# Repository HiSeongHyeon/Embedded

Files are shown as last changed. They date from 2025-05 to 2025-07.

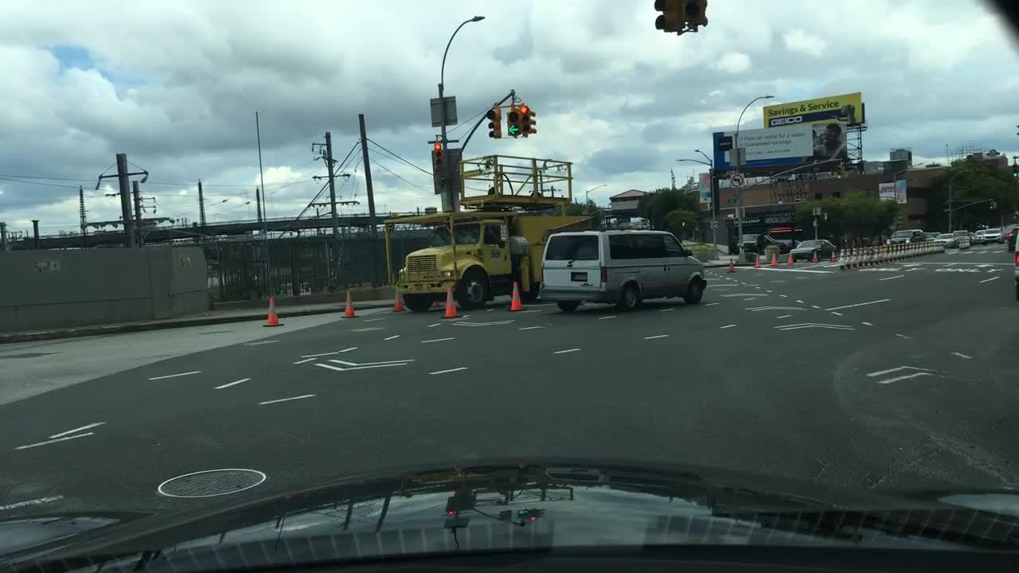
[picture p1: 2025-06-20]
src_tmp/src/glare_detection/src/test_images/00c41a61-4ba25ad4_jpg.rf.0ae1f0196ada40d85010ea932c0ebc6e.jpg

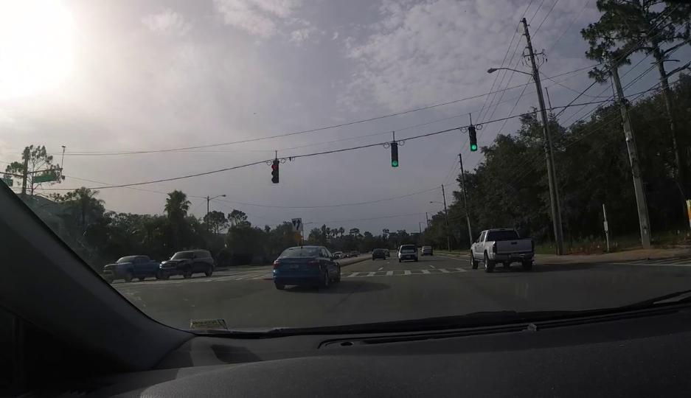
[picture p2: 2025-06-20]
src_tmp/src/glare_detection/src/test_images/vid-7-_png.rf.13047234f4ee9584bf44184de06c9a75.jpg

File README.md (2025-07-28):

# 🚗 SunVisorRobot: 차량 운전자 눈부심 방지 선바이저 로봇

**차량 운전 중 발생하는 태양 및 강한 조명으로 인한 눈부심(Glare)을 자동으로 감지하고, 지능적으로 선바이저를 제어하여 운전자의 시야를 안전하게 확보하는 임베디드 시스템 프로젝트입니다.**

## 🌟 프로젝트 목표

*   실시간으로 변화하는 외부 조명 환경에서 Glare를 정확하게 인식합니다.
*   카메라로 인식된 Glare의 위치를 운전자 시야 기준으로 정밀하게 좌표 변환합니다.
*   변환된 좌표에 따라 선바이저를 3x3 그리드 영역으로 신속하고 정확하게 이동시켜 효과적으로 눈부심을 차단합니다.
*   Raspberry Pi에서 고수준 인식 및 판단을, Arduino에서 저수준 모터 제어를 담당하는 분산 시스템으로 구현하여 실시간성과 안정성을 확보합니다.

## 🛠️ 시스템 아키텍처

본 시스템은 크게 다음과 같은 모듈로 구성됩니다:

1.  **Glare 감지 모듈 (C++ on Raspberry Pi):**
    *   Raspberry Pi 카메라 모듈 v3로부터 실시간 영상 스트림을 입력받습니다.
    *   OpenCV 라이브러리를 사용하여 HSV 색 공간 변환, 임계값 필터링, Contour 분석 등을 통해 이미지 내 Glare 영역을 탐지하고 중심 픽셀 좌표를 추출합니다.
2.  **좌표 변환 모듈 (C++ on Raspberry Pi):**
    *   Glare 감지 모듈에서 전달받은 픽셀 좌표를 입력으로 사용합니다.
    *   카메라 내부 파라미터, 렌즈 왜곡 계수, 차량 내 카메라/운전자/윈드실드의 3D 기하학적 관계를 이용하여 픽셀 좌표를 3x3 그리드 좌표 `(col, row)`로 변환합니다.
3.  **시리얼 통신 모듈 (C++ on Raspberry Pi & Arduino):**
    *   Raspberry Pi에서 Arduino로 제어 명령을 전송합니다.
    *   1바이트 통신 프로토콜 사용:
        *   비트 7: Glare 감지 유무 (1: 감지, 0: 미감지/접기)
        *   비트 6-4: 예약
        *   비트 3-2: 컬럼(Col, x) 좌표 (0-2, 2비트)
        *   비트 1-0: 로우(Row, y) 좌표 (0-2, 2비트)
4.  **모터 제어 모듈 (Arduino):**
    *   RPi로부터 수신된 1바이트 명령을 해석합니다.
    *   해석된 그리드 좌표에 따라 스텝 모터와 서보 모터를 제어하여 선바이저를 해당 위치로 이동시킵니다.

## 🌳 프로젝트 디렉토리 구조

```
Embedded/
├── .gitignore
├── README.md
│
├── src/ # 소스 코드 루트
│ ├── glare_detection/ # Glare 감지 및 메인 제어 루프
│ │ ├── CMakeLists.txt
│ │ ├── include/ (SunDetector.h, return_position.h)
│ │ └── src/ (SunDetector.cpp, return_position.cpp, main.cpp)
│ │
│ ├── coordinate_mapping/ # 좌표 변환 모듈
│ │ ├── CMakeLists.txt
│ │ ├── include/ (config.hpp, coordinates.hpp, get_grid_size.hpp)
│ │ └── src/ (coordinates.cpp, test_visualization.cpp 등)
│ │
│ └── serial_communication/ # 시리얼 통신 모듈
│   ├── CMakeLists.txt
│   ├── include/ (serial_communication.hpp)
│   └── src/ (serial_communication.cpp)
│
├── CAD/ # HW 제작 CAD 파일
│  
└── arduino/ # Arduino 모터 제어 코드
```

## ⚙️ 개발 환경 및 필수 설치 요소

*   **하드웨어:**
    *   Raspberry Pi 5 (또는 상위 모델)
    *   Raspberry Pi 카메라 모듈 v3
    *   Arduino Mega 2560 (또는 호환 보드)
    *   스텝 모터 및 드라이버
    *   서보 모터
    *   기타 전원 공급 장치, 회로 부품
*   **소프트웨어 (Raspberry Pi):**
    *   Raspberry Pi OS (Debian 기반 Linux)
    *   C++ 컴파일러 (g++ 7.5.0 이상, C++17 지원)
    *   CMake (3.10 이상)
    *   OpenCV 개발 라이브러리 (`libopencv-dev`)
    *   Python 3.x (주로 빌드 스크립트, 테스트 또는 유틸리티용)
    *   pip (Python 패키지 관리자)
    *   PlatformIO Core (예시/Arduino 코드 빌드 및 업로드용, `pip install platformio`로 설치)
    *   Git
*   **소프트웨어 (개발용 PC - 선택적):**
    *   C++ IDE (VS Code with CMake Tools, CLion 등)
    *   Arduino IDE 또는 PlatformIO IDE (VS Code 확장)

## 🚀 설정, 빌드 및 실행 방법

**1. 소스 코드 클론:**
```bash
git clone https://github.com/HiSeongHyeon/Embedded.git
cd Embedded
```

**2. 필수 패키지 설치 (Raspberry Pi 터미널에서):**
```bash
sudo apt update
sudo apt install build-essential g++ cmake libopencv-dev python3-opencv python3-pip git
```

**3. 개별 빌드 및 실행 (수동으로 진행할 경우):**

*   **C++ 모듈 (Glare 감지 및 메인 제어):**
    ```bash
    cd Embedded # 프로젝트 루트 (최상위 CMakeLists.txt가 있는 곳)
    mkdir build && cd build
    cmake ..
    make
    # 실행 (예시)
    ./src/glare_detection/glareTracker
    ```

*   **실행 전 아래와 같은 Arduino 업데이트 필수**
    ```bash
    cd arduino
    pio run # 빌드 (예시/다른 IDE 사용 가능)
    pio run -t upload # 업로드 (포트 자동 감지 또는 platformio.ini에 지정)
    ```

## 📽️ 시연 영상
프로젝트의 작동 방식을 아래 영상으로 확인해보세요.

시연 영상 (https://www.youtube.com/watch?v=Lcjh1zH9KA4)

## 👏 포스터
포스터

## 🤝 팀원

*   **최성현 (팀장): doq1324@uos.ac.kr**
*   **이종현: whdgus985@uos.ac.kr**
*   **오정택: wjdxor9534@uos.ac.kr**
*   **조경호: vitus00@uos.ac.kr**
*   **조민규: gyull911@uos.ac.kr**

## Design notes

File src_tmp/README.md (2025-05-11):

# 임시 통합

## 프로젝트 구조

```
src_tmp/                    # 프로젝트 최상위 디렉토리리
├── CMakeLists.txt          # CMakeLists 파일일
├── src/                    
│   ├── coordinate_mapping/     # 좌표 변환 모듈
│   ├── glare_detection/        # glare 인식 모듈
│   ├── serial_communication/   # 시리얼 통신 모듈
└── build/              
    └── src         
        └── ...     # 각 모듈별 실행파일 여기에
```

---

## 빌드 방법

```bash
cd src_tmp/build
cmake ..
make
```

## 실행 방법 (예시: main 함수)

```bash
cd src_tmp/build/src/glare_detection
./solarTracker
```

---

## TODO

- [ ] 카메라 있는 환경에서 잘 돌아가는지 체크
- [ ] 시리얼 통신 추가

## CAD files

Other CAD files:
CAD/Link/dm-s2000md 서보모터 캐드파일/DoMan DM-S2000MD.stp
CAD/Rail_combined/Rail_lower_case.stp
CAD/sg90-micro-servo-9g-tower-pro-1.snapshot.3/SG90 - Micro Servo 9g - Tower Pro.5.SLDPRT
CAD/Rail_combined/Rail_pully_cover_reverse.stp
CAD/sg90-micro-servo-9g-tower-pro-1.snapshot.3/SG90 - Micro Servo 9g - Tower Pro.6.SLDPRT
CAD/Rail_combined/Rail_pully_cover.stp
CAD/sg90-micro-servo-9g-tower-pro-1.snapshot.3/SG90 - Micro Servo 9g - Tower Pro.4.SLDPRT
CAD/sg90-micro-servo-9g-tower-pro-1.snapshot.3/SG90 - Micro Servo 9g - Tower Pro.2.SLDPRT
CAD/sg90-micro-servo-9g-tower-pro-1.snapshot.3/SG90 - Micro Servo 9g - Tower Pro.1.SLDPRT
CAD/sg90-micro-servo-9g-tower-pro-1.snapshot.3/SG90 - Micro Servo 9g - Tower Pro.STEP
CAD/sg90-micro-servo-9g-tower-pro-1.snapshot.3/SG90 - Micro Servo 9g - Tower Pro.3.SLDPRT
CAD/Control_box/LRS-100-12.ipt
CAD/Control_box/Main_box.ipt
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

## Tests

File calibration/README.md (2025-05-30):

# Raspberry Pi 카메라 체커보드 캘리브레이션 스크립트

이 Python 스크립트는 Raspberry Pi에서 **picamera2** 또는 일반 **OpenCV VideoCapture** 카메라를 사용하여 **체커보드 기반 카메라 캘리브레이션**을 수행하는 도구입니다. OpenCV의 `cv2.calibrateCamera()`를 활용하며, 결과를 `config.hpp` 형식으로 출력해 외부 C++ 프로젝트에서 사용할 수 있도록 지원합니다.

---

## 📌 주요 기능

- 체커보드 이미지 캡처
- 체커보드 코너 검출 및 시각화
- 3D-2D 포인트 수집 및 캘리브레이션
- 카메라 내부 행렬 및 왜곡 계수 추정
- 평균 재투영 오차 계산
- `config.hpp` 형태로 결과 출력

---

## 📁 파일 구조

```
calibration_images/      # 캘리브레이션 이미지가 저장되는 폴더 (자동 생성)
calibrate_camera.py      # 본 Python 스크립트
```

---

## ⚙️ 요구사항

### Python 패키지
- `numpy`
- `opencv-python`
- `picamera2`

설치 명령:
```bash
pip install numpy opencv-python
sudo apt install python3-picamera2
```

### 체커보드 준비
- 내부 코너 수: 예) 9x6 체커보드라면 `가로 8`, `세로 5`로 설정
- 각 칸 크기(mm): 실제 사용한 체커보드 칸의 물리적 길이 (예: 25.0 mm)

---

## 🚀 실행 방법

```bash
python3 calibrate_camera.py
```

### 실행 중 조작
- **스페이스바**: 이미지 캡처  
- **ESC**: 수동 종료  

총 `NUM_IMAGES_TO_CAPTURE` 개수만큼 캡처되면 자동 종료 후 캘리브레이션 수행

---

## ⚙️ 설정 변경 (코드 상단)

```python
CHECKERBOARD_WIDTH = 8         # 내부 가로 코너 수
CHECKERBOARD_HEIGHT = 5        # 내부 세로 코너 수
SQUARE_SIZE_MM = 25.0          # 칸 하나의 실제 길이 (mm)
NUM_IMAGES_TO_CAPTURE = 20     # 수집할 이미지 수
IMAGE_SAVE_PATH = "./calibration_images/"  # 저장 경로
```

---

## 📤 출력 예시

캘리브레이션 성공 시, 다음 형식으로 결과 출력됨:

```cpp
const cv::Mat DEFAULT_CAMERA_MATRIX = (cv::Mat_<double>(3, 3) <<
    fx, 0, cx,
    0, fy, cy,
    0, 0, 1);

const cv::Mat DEFAULT_DISTORTION_COEFFICIENTS = (cv::Mat_<double>(1, 5) <<
    k1, k2, p1, p2, k3);
```

→ C++ 프로젝트에 복붙하여 바로 활용 가능

---

## ✅ 참고 사항

- 최소 10장 이상의 다양한 각도/거리에서 촬영된 이미지가 필요합니다 (권장: 15~25장).
- 체커보드는 프레임 안에서 **기울어지고**, **작아지고**, **가장자리로 치우치는** 조건으로 다양하게 찍을수록 정확도가 올라갑니다.

---

## 🔚 종료 시

- `ESC`를 누르거나 오류 발생 시 종료됨
- 종료 후 `calibration_images/` 폴더에 캡처 이미지가 저장됩니다

---

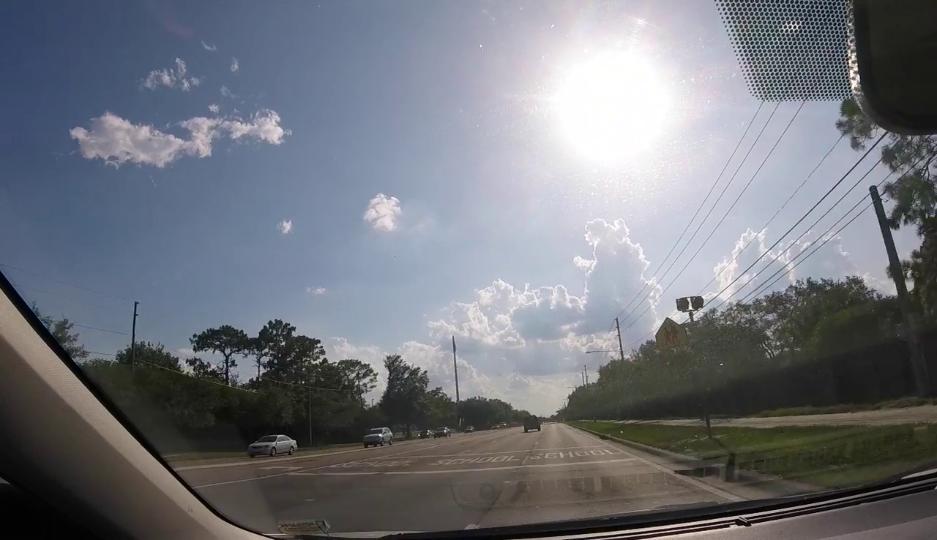
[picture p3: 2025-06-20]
src_tmp/src/glare_detection/src/test_images/vid-4_png.rf.a531ffbc7d8a61b64c2c81a6e4ef92cb.jpg

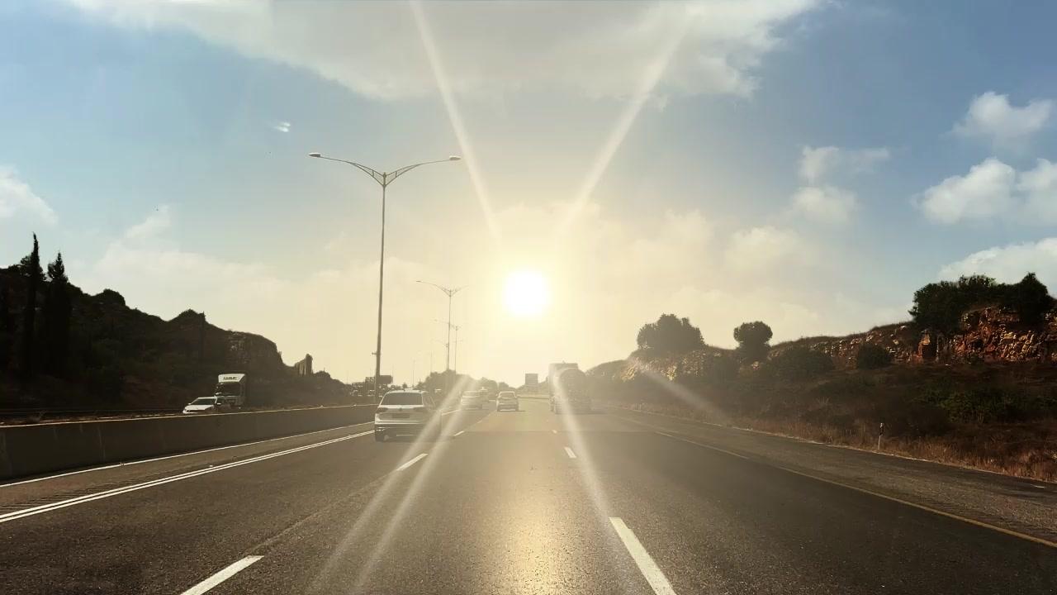
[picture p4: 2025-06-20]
src_tmp/src/glare_detection/src/test_images/frame_004500_jpg.rf.e0c76d7ce57c642a398b2b6f583553d5.jpg

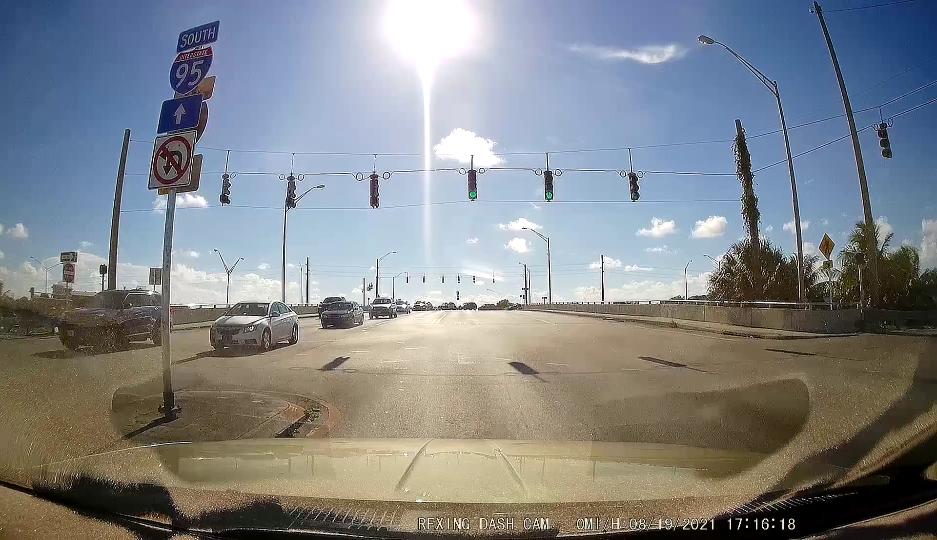
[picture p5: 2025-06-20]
src_tmp/src/glare_detection/src/test_images/vid-14_png.rf.9b8568660f613ee20e3fe82dc9cdfaeb.jpg

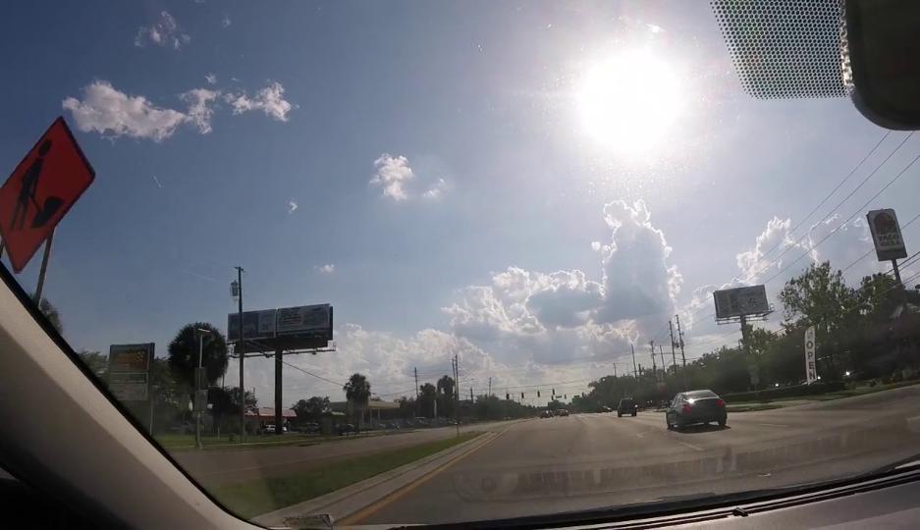
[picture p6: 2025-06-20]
src_tmp/src/glare_detection/src/test_images/GOPR0457-converted-006-workersAhead-start2920_mp4_image13_png.rf.2c95d19a40ebd916a5f1d5eb9f40ea5b.jpg

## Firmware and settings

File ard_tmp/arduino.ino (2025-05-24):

#include <Servo.h>

// ----------- 핀번호 설정 --------------
// 부저
#define buzzer 4

// 서보모터
#define Servo_main 2
#define Servo_mini 3

// 스텝모터
#define dir_1 28
#define steps_1 5
#define ms1_1 6
#define ms2_1 7
#define ms3_1 8
#define dir_2 9
#define steps_2 10
#define ms1_2 11
#define ms2_2 12
#define ms3_2 13

// ------------ 서보모터 제어 설정 ------------------
Servo mainServo;
Servo miniServo;

// ------------- 부저 멜로디 설정 ---------------------
int arraySize = 5;
int melody[] = {245, 260, 292, 328, 348, 390, 439, 492, 523, 586, 1317};
int song1[]   = {1, 2, 3, 4, 5};
int song2[]   = {5, 4, 3, 2, 1};
int noteDuration[] = {2, 2, 2, 2, 2};

// ------------- 위치 테이블 (1~9) ---------------------
int positionTable[9][2] = {
  {-1200,    0},   // 1
  {-600,   600},   // 2
  {   0,  1200},   // 3
  {-850,    0},    // 4
  {-425,  425},    // 5
  {   0,  850},    // 6
  {-400,    0},    // 7
  {-200,  200},    // 8
  {   0,  400}     // 9
};

// 위치 추적 변수
int position_left  = -600;   // 왼쪽 모터의 현재 위치 (음수)
int position_right = 600;    // 오른쪽 모터의 현재 위치 (양수)
int currentIndex = 0; // 최신 위치 (1번째)

// 글래어 디텍트 이전상태 저장 변수
bool prevGlareDetected = false;   // 이전 루프에서의 값 (초기값은 false)

// =========================================================================================

// ▼▼▼▼▼ 테스트용 더미 코드 활성화/비활성화 ▼▼▼▼▼
// #define ENABLE_ASCII_DEBUG_INPUT // 이 줄을 주석 처리하면 RPi와의 1바이트 통신 모드로 작동

void setup() {
  // 서보모터
  mainServo.attach(Servo_main);
  miniServo.attach(Servo_mini);

  // 스텝모터
  pinMode(dir_1, OUTPUT); pinMode(steps_1, OUTPUT);
  pinMode(ms1_1, OUTPUT); pinMode(ms2_1, OUTPUT); pinMode(ms3_1, OUTPUT);
  pinMode(dir_2, OUTPUT); pinMode(steps_2, OUTPUT);
  pinMode(ms1_2, OUTPUT); pinMode(ms2_2, OUTPUT); pinMode(ms3_2, OUTPUT);
  digitalWrite(ms1_1, LOW); digitalWrite(ms2_1, LOW); digitalWrite(ms3_1, HIGH);
  digitalWrite(ms1_2, LOW); digitalWrite(ms2_2, LOW); digitalWrite(ms3_2, HIGH);

  // 부저
  pinMode(buzzer, OUTPUT);

  Serial.begin(115200);
  delay(100);


  // Serial 통신 시작
  #ifdef ENABLE_ASCII_DEBUG_INPUT
    Serial.println("ASCII Debug Input Mode: Send '0' to retract, '1'-'9' for grid.");
  #else
    Serial.println("RPi Communication Mode: Waiting for 1-byte command.");
  #endif
}

// ------------------------- 스텝모터 위치 제어 ----------------------------

void moveTo(int target_left, int target_right) {
  int steps_needed = abs(target_left - position_left);  // 동일 스텝 수 가정
  bool dir_left = (target_left > position_left) ? HIGH : LOW;
  bool dir_right = (target_right > position_right) ? HIGH : LOW;

  digitalWrite(dir_1, dir_left);
  digitalWrite(dir_2, dir_right);

  for (int i = 0; i < steps_needed; i++) {
    digitalWrite(steps_1, HIGH);
    digitalWrite(steps_2, HIGH);
    delayMicroseconds(1600);
    digitalWrite(steps_1, LOW);
    digitalWrite(steps_2, LOW);
    delayMicroseconds(1600);

    position_left  += (dir_left == HIGH) ? 1 : -1;
    position_right += (dir_right == HIGH) ? 1 : -1;
  }
}

// ----------------------- 계단식 이동 구현 -----------------------------

void moveToGridPosition(int targetIndex) {
  int curRow = currentIndex / 3;
  int curCol = currentIndex % 3;
  int tgtRow = targetIndex / 3;
  int tgtCol = targetIndex % 3;

  // 1단계: 현재 층의 중간으로 이동
  if (curCol != 1) {
    int midIndex = curRow * 3 + 1;
    moveTo(positionTable[midIndex][0], positionTable[midIndex][1]);
    currentIndex = midIndex;
  }
  delay(500);

  // 2단계: 다른 층의 중간으로 이동
  if ((currentIndex / 3) != tgtRow) {
    int tgtMidIndex = tgtRow * 3 + 1;
    moveTo(positionTable[tgtMidIndex][0], positionTable[tgtMidIndex][1]);
    currentIndex = tgtMidIndex;
  }
  delay(500);

  // 3단계: 최종 복구
  if (currentIndex != targetIndex) {
    moveTo(positionTable[targetIndex][0], positionTable[targetIndex][1]);
    currentIndex = targetIndex;
  }
}

// ----------------------- 썬가드 작동 함수 -----------------------------
void sungard_down() {
  for (int note = 0; note < arraySize; note++){
    int duration = 700/noteDuration[note];
    tone(buzzer, melody[song1[note]], duration);
    delay(duration+30);
  }
  delay(500);
  for (int i = 110; i >=0; i--) {
        mainServo.write(i);
        delay(10);
  }
}

void sungard_up() {
  for (int note2 = 0; note2 < arraySize; note2++){
    int duration2 = 700/noteDuration[note2];
    tone(buzzer, melody[song2[note2]], duration2);
    delay(duration2+30);
  }
  delay(500);
  for (int i = 0; i <= 110; i++) {
        mainServo.write(i);
        delay(10);
  }
}

// ----------------------- 미니서보 작동 함수 -----------------------------
void minisurvo_out() {
  for (int i = 0; i <= 90; i++) {
    miniServo.write(i);
    delay(10);
  }
}

void minisurvo_in() {
  for (int i = 90; i >= 0; i--) {
    miniServo.write(i);
    delay(10);
  }
}

// =========================================================================================

int get_grid_coords(int index) {
  switch(index) {
    case 0b0000: return 3;
    case 0b0100: return 2;
    case 0b1000: return 1;
    case 0b0001: return 6;
    case 0b0101: return 5;
    case 0b1001: return 4;
    case 0b0010: return 9;
    case 0b0110: return 8;
    case 0b1010: return 7;
    default: return 0;
  }
}
// grid_coords (1~9)
// 1 2 3
// 4 5 6
// 7 8 9

// =========================================================================================
void loop() {
  byte receivedByte = 0; // 처리할 최종 명령 바이트, 기본값은 Glare 없음 (접기)
  bool newDataToProcess = false; // 새로운 유효한 명령이 있는지 여부

  // --------------------------------------------------------------------
  // 데이터 수신 및 receivedByte 설정 (모드에 따라 분기)
  // --------------------------------------------------------------------
  #ifdef ENABLE_ASCII_DEBUG_INPUT
    // --- ASCII 문자 디버그 입력 처리 ---
    if (Serial.available() > 0) {
      byte asciiInput = Serial.read(); // 일단 읽음
      // 버퍼에 남은 다른 문자들 비우기 (가장 마지막 입력만 고려)
      while (Serial.available() > 0) {
        asciiInput = Serial.read();
      }

      Serial.print("ASCII Debug Input: '");
      Serial.write(asciiInput);
      Serial.print("' (DEC: ");
      Serial.print(asciiInput, DEC);
      Serial.println(")");

      if (asciiInput >= '1' && asciiInput <= '9') {
        int grid_target_1_to_9 = asciiInput - '0'; // 정수 1~9로 변환

        // 명령 바이트 생성: Glare 감지(1) + 그리드 인덱스
        receivedByte = (1 << 7) | (static_cast<byte>(grid_target_1_to_9) & 0x0F);
        newDataToProcess = true;
        Serial.print("  ASCII Debug: Glare ON, Grid Index: ");
        Serial.println(grid_target_1_to_9);

      } else if (asciiInput == '0') {
        // 명령 바이트 생성: Glare 없음 (0)
        receivedByte = 0; // 00000000
        newDataToProcess = true;
        Serial.println("  ASCII Debug: Glare OFF (Retract)");
      } else {
        // 유효하지 않은 ASCII 입력은 무시 (newDataToProcess = false 유지)
        Serial.println("  ASCII Debug: Unknown input, no action.");
      }
    }

  #else
    // --- RPi 1바이트 통신 처리 ---
    byte latestRPiByte = 0; // RPi에서 온 가장 마지막 바이트
    bool rpiDataAvailable = false;

    while (Serial.available() > 0) {
      latestRPiByte = Serial.read();
      rpiDataAvailable = true;
    }

    if (rpiDataAvailable) {
      receivedByte = latestRPiByte; // RPi에서 온 값을 최종 처리할 바이트로 설정
      newDataToProcess = true;

      Serial.print("RPi Byte Received: 0b");
      for (int i = 7; i >= 0; i--) {
        Serial.print((receivedByte >> i) & 0x01);
        if (i == 7) Serial.print(" ");
        if (i == 4) Serial.print("_");
        if (i == 2 && i > 0) Serial.print(" ");
      }
      Serial.print(" (Decimal: ");
      Serial.print(receivedByte);
      Serial.println(")");
    }
  #endif
  // --------------------------------------------------------------------
  // 데이터 수신 및 receivedByte 설정 끝
  // --------------------------------------------------------------------


  // ▼▼▼▼▼ 공통 처리 로직 시작 (newDataToProcess가 true일 때만 실행) ▼▼▼▼▼
  if (newDataToProcess) {
    // 최상위 비트(MSB, 비트 7)를 추출하여 Glare 감지 유무 판단
    bool glareDetectedBySerial = (receivedByte >> 7) & 0x01;

    if (!prevGlareDetected && glareDetectedBySerial) {
      // 0 → 1 로 바뀐 경우
      Serial.println("  Glare DETECTED (rising edge)");

      minisurvo_out();
      delay(500);
      sungard_down();
    }

    else if (prevGlareDetected && !glareDetectedBySerial) {
      // 1 → 0 로 바뀐 경우
      Serial.println("  Glare CLEARED (falling edge)");

      moveToGridPosition(1);

      sungard_up();
      delay(500);
      minisurvo_in();
    }

    // 글래어가 식별될 경우
    if (glareDetectedBySerial) {
      // Glare가 감지된 경우 (최상위 비트가 1)
      // 하위 4비트(비트 0-3)를 추출하여 그리드 인덱스 얻기
      int gridIndexFromSerial = receivedByte & 0x0F; // 00001111 마스크
      Serial.print("  Serial Command: Glare DETECTED. Grid Index: ");
      Serial.println(gridIndexFromSerial);

      int grid_coords = get_grid_coords(gridIndexFromSerial);

      #ifdef ENABLE_ASCII_DEBUG_INPUT
        if (gridIndexFromSerial >= 1 && gridIndexFromSerial <= 9) {
            moveToGridPosition(gridIndexFromSerial - 1);  // 인덱스 0~8
        }
        else {
            Serial.println("Invalid command.");
        }

      #else
        if (grid_coords >= 1 && grid_coords <= 9) {
            moveToGridPosition(grid_coords - 1);  // 인덱스 0~8
        }
        else {
            Serial.println("Invalid command.");
        }
     
      #endif
    }
    // 상태 저장
    prevGlareDetected = glareDetectedBySerial;
  }
}

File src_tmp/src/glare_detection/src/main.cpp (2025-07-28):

#define GRID_TEST // 그리드 좌표 테스트 모듈 활성화

#include <return_position.h>
#include <opencv2/opencv.hpp>
#include <iostream>
#include <cstdio>
#include <vector>
#include <string>
#include <chrono>

// 추가
#include <utility> // std::pair
#include <string>

// --- 좌표 변환 및 시리얼 통신 모듈 헤더 ---
#include "config.hpp"
#include "coordinates.hpp" // camera_to_driver_coords, to_bit_list
#include "get_grid_size.hpp"
#include "serial_communication.hpp"

#include <cstdlib>

using namespace std;
using namespace cv;
using namespace std::chrono;

// 프로그램 종료 시 시리얼 포트 자동 닫기를 위한 핸들러
void cleanup_serial_main_handler() { SerialCom::closePort(); }

int main() {
    cv::setNumThreads(cv::getNumberOfCPUs()); // CPU 최대 활용

    glare_position gp;
    glare_detector gd;
    position_queue pq;

    cv::Point2f glarePos;
    cv::Point2f avg_glarePos = {0, 0};

    // // 시리얼 포트 초기화
    // const char *arduino_port = "/dev/ttyACM0"; // <<--- 실제 Arduino 포트
    // if (!SerialCom::initialize(arduino_port, B9600)) { // Baud rate 9600
    //     cerr << "Error: Failed to initialize serial port " << arduino_port << endl;
    // return -1; // 시리얼 포트 열기 실패 시 종료
    // }
    // atexit(cleanup_serial_main_handler); // 프로그램 종료 시 포트 자동 닫기 등록
    // cout << "[Serial] Port " << arduino_port << " opened successfully." << endl;

    bool debug_mode = true;
    // 0.2 -> 0.8
    const double brightness_threshold = 0.2;
    const double stddev_threshold = 0.5;

    // // 기존 카메라 스트림 코드
    // const char* cmd =
    //     "libcamera-vid -t 0 -n --width 1280 --height 480 --codec mjpeg -o - 2>/dev/null | "
    //     // "ffmpeg -f mjpeg -i - -f image2pipe -vcodec copy -";
    //     "ffmpeg -f mjpeg -analyzeduration 10000000 -probesize 10000000 -i - -f image2pipe -vcodec copy -";

    // 노출 수동 조절 코드
    const char* cmd =
        "libcamera-vid -t 0 -n --width 1280 --height 480 --framerate 10 " 
        "--shutter 6000 --gain 1.0 --awbgains 1.2,1.2 "
        "--codec mjpeg -o - 2>/dev/null | "
        "stdbuf -o0 ffmpeg -loglevel quiet -f mjpeg -analyzeduration 10000000 -probesize 10000000 "
        "-i - -f image2pipe -vcodec copy -";


    FILE* pipe = popen(cmd, "r");
    if (!pipe) {
        cerr << "ffmpeg 실행 실패\n";
        return -1;
    }

    vector<uchar> buffer;
    int c;
    bool start_found = false;
    bool first_frame = true;

    while (true) {
        ////////////////////      카메라 파이프 연결      ////////////////////
        buffer.clear();
        start_found = false;

        while ((c = fgetc(pipe)) != EOF) {
            buffer.push_back((uchar)c);

            if (!start_found && buffer.size() >= 2 &&
                buffer[buffer.size() - 2] == 0xFF && buffer[buffer.size() - 1] == 0xD8) {
                start_found = true;
            }

            if (start_found && buffer.size() >= 2 &&
                buffer[buffer.size() - 2] == 0xFF && buffer[buffer.size() - 1] == 0xD9) {
                break;
            }
        }

        if (feof(pipe)) {
            cerr << "파이프 종료됨\n";
            break;
        }

        if (buffer.size() < 100) continue;

        Mat jpegData(buffer);
        Mat frame = imdecode(jpegData, IMREAD_COLOR);
        if (frame.empty()) continue;

        if (first_frame) {
            gp.gd.startVideo(frame);
            first_frame = false;
        }
        //////////////////////////////////////////////////////////////////////
        
        // glare detect 시간, 실행시간 측정 시작
        auto start = high_resolution_clock::now();

        auto brightness = gd.isBrightArea(frame);
        auto stddev = gd.isStandardArea(frame);

        // cout << "brightness: "<< brightness << ", stddev: "<< stddev << "\n";

        // check foward brightness state, 차량 전방 밝기 상태와 표준 편차를 동시에 고려
        // 밝은 곳 or 표준편차가 큰 곳(태양에 의한 과도한 노출 조정 or 그림자 고려)
        if (brightness > brightness_threshold || stddev > stddev_threshold) {
            // intensity, saturation, contrast에 따라 gphoto map 생성
            cv::Mat gphoto = gd.computePhotometricMap(frame);

            // gphoto map 상에서 원형의 glare를 찾아 ggeo map 생성
            cv::Mat ggeo = gd.computeGeometricMap(gphoto);

            // gphoto, ggeo map에 따라 priority 부여
            cv::Mat priority = gd.computePriorityMap(gphoto, ggeo);

            // priority에 따라 찾은 glare의 좌표 반환
            glarePos = gp.getPriorityBasedGlareCenter(priority, gphoto, ggeo, gd);

            // glare detect 시간 측정 종료
            auto detect_end = high_resolution_clock::now();
            auto detect_duration = duration_cast<milliseconds>(detect_end - start).count();
            cout << "Detect Processing time: " << detect_duration << " ms\n"; 
            
            // glare의 좌표가 유효한 지 여부에 따라 queue에 저장 후 glare의 평균 좌표 반환
            pq.push(glarePos);
            if (pq.shouldReturnAverage() == 1) {        // glare가 존재하는 경우. glare의 평균 좌표 최신화
                avg_glarePos = pq.getAvgCoord();
            }
            else if (pq.shouldReturnAverage() == 0){    // glare가 잠깐 사라진 경우. 바로 선바이저가 접히는 것을 방지하기 위해 glare 평균 좌표 유지
                continue;
            }
            else{                                       // glare가 존재하지 않는 경우. 유효하지 않은 좌표 반환
                avg_glarePos = {-1, -1};
            }
            
            // cout << pq.shouldReturnAverage() << "\n";

            // debug_mode가 True, glare의 좌표가 양수(카메라 프레임 내에 존재할 경우)일 때 원으로 표시
            if (debug_mode && glarePos.x > 0) {
                cv::circle(frame, glarePos, 10, cv::Scalar(255, 0, debug_color), 2);
                cout << "Detected glare position: (" << glarePos.x << ", " << glarePos.y << ")\n";
                cout << "Detected avg glare position: (" << avg_glarePos.x << ", " << avg_glarePos.y << ")\n";

            } 

        } 
        // 어두운 곳이면서 표준 편차가 작은 곳(카메라가 빛을 정면으로 촬영하지 않을 때)
        else{
            avg_glarePos = {-1, -1};
        }

        // 카메라 기준 coord -> 운전자 기준 coord로 변환
        bool glare_is_detected_flag = (avg_glarePos.x != -1 && avg_glarePos.y != -1);
        std::pair<int, int> grid_coords = {-1, -1};
        std::vector<int> bit_list_for_grid;

        static bool prev_detected_flag = false;
        static std::pair<int, int> prev_grid_coords = {-2, -2};

        if (glare_is_detected_flag) {
            std::pair<double, double> sun_center_for_transform = {
                static_cast<double>(avg_glarePos.x),
                static_cast<double>(avg_glarePos.y)};
            grid_coords = camera_to_driver_coords(sun_center_for_transform);

            std::vector<int> bit_list = to_bit_list(grid_coords);
            bit_list_for_grid = bit_list;
        }

        // // Arduino 명령 바이트 생성 및 전송
        // if (!SerialCom::sendCommandToArduino(glare_is_detected_flag, grid_coords)) {
        //         cerr << "[Main] Error: Failed to send command to Arduino via SerialCom module." << endl;
        // }
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

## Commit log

2025-04-09 chore: initial commit
    - 초기 프로젝트 구조 구축
    - sunvisor_system, tests 폴더 생성 및 기본 모듈/테스트 파일 추가
    - .gitignore, .gitattributes, .pre-commit-config.yaml, .gitmessage 파일 추가
2025-04-10 chore: /sunvisor_system/을 /src/sunvisor_system/으로 이동
2025-04-10 docs: 사용 방법 명시
2025-04-10 docs: 초기 파일 설명 추가
2025-04-10 docs: pytest 추가
2025-04-17 docs: 라이브러리들의 버전 명시 삭제
2025-04-17 docs: sunvisor_system.py의 이름 변경으로 인한 설명 변경
2025-04-17 feat: 그리드 좌표를 4비트 길이의 리스트로 변환해주는 함수 추가
2025-04-17 docs: 주석의 애매한 설명 명확하게 수정
2025-04-17 chore: sunvisor_system의 메인 함수 이름 재지정
2025-04-17 chore: 메인함수 이름 재지정에 따른 삭제
2025-04-17 fix: Rectangle 함수에서 키워드 인자값을 잘못 설정했던 오류 수정
2025-04-17 chore: 그리드 사이즈 4,3으로 변경
2025-04-17 test: 시각화 함수에 대한 테스트 코드 추가 및 상수값 수정
2025-04-18 feat: glare 인식 코드 구현
    라즈베리파이 상에서 카메라 모듈을 통해 영상 정보를 수집하고, openCV를 활용하여 glare의 존재 및 위치 좌표를 반환하는 cpp코드 구현
2025-04-25 fix: import 위치 정확히 명시
2025-04-25 test: 더미 함수 생성
2025-04-25 docs: 각 라이브러리 버전 명시
2025-05-06 style: 좌표계 통일
2025-05-06 style: 좌표계 통일 및 방향 벡터 좌표계 따로 설정
2025-05-06 test: 테스트 코드 포맷팅 수정
2025-05-11 feat: 좌표변환 모듈 c++ 재작성 및 임시 통합
2025-05-11 docs: 현 진행상황 공유
2025-05-11 feat: 시리얼 통신 추가한 임시 메인 함수
2025-05-11 refactor: 그리드 사이즈 3x3으로 변경
2025-05-11 refactor: 시리얼 통신 프로토콜 명확히 수정
    [arduino.ino]
2025-05-13 feat: 좌표변환 모듈 및 glare 인식 모듈 1차 통합
2025-05-13 feat: 좌표 변환 및 glare 인식 모듈 2차 통합
2025-05-13 fix: position queue 메소드 수정
    누락된 코드 추가하여 (0, 0)만 반환하는 오류 수정
2025-05-13 feat: 시리얼 통신 시 버퍼 비우는 while문 추가
2025-05-13 feat: 시리얼 버퍼 초기화 구문 추가
2025-05-14 fix: contrast 계산 방법 수정 및 glare 영역 추출 방식 수정
    1. contrast 계산을 boxfilter 사용
    2. glare를 계산할 때 가장 밝은 픽셀 좌표를 반환하는 것이 아닌 밝으면서 가장 큰 영역의 중심 좌표를 추출하도록 수정
    [main.cpp]
2025-05-19 fix: debugging용 코드 추가
    [main.cpp]
2025-05-19 fix : debugging 코드 추가 2
    [main.cpp]
2025-05-19 feat: 시리얼 통신 활성화화
2025-05-19 fix : debugging 코드 3차 추가가
    [main.cpp]
2025-05-19 feat : 카메라 좌우 반전 코드 추가가
2025-05-19 feat : 카메라 좌우 반전 추가 항목 제거
2025-05-19 feat: 비디오 활용 코드 추가 및 디버깅 용 전역변수 추가
    1. 비디오를 통해 코드 테스트를 진행하기 위한 코드 추가
    2. priority별 색상 구분을 위한 전역변수 debug_color 추가
2025-05-19 fix: glare detect 파라미터 값 수정 및 디버깅 코드 수정, 오류 수정
    1. glare detect에 사용되는 파라미터인 밝기 정보와 원형 여부 Threshold 수정
    2. 유효하지 않은 좌표를 반환할 때 케이스 별로 반환되는 좌표 값을 달리하도록 수정
    3. 카메라 스트리밍 pipe broken error 수정
    [main.cpp]
2025-05-20 fix: glare detect 안되는 현상 원인 파악
    프레임 내 아무런 좌표도 찾아내지 못하는 현상의 원인을 찾기 위해 브랜치를 새로 만들고 코드 수정
    [main.cpp]
2025-05-20 feat: test dataset 사용을 위해 메인함수 모드 추가
    fix: glare detect 파라미터 및 코드 수정
    1. 카메라 활용 모드/ 비디오 활용 모드/ test dataset 활용 모드에 따라 define 매크로 추가
    2. queue에서 초기값을 항상 무시하던 것에서 초기값은 항상 유효 값으로 받도록 수정함. 첫 좌표가 반영되지 않아 계속 좌표를 찾지 못하던 상황을 개선
    [main.cpp]
2025-05-23 fix: avg_glarePos 반환 안되는 오류 수정 feat: 카메라의 노출을 수동으로 수정하는 코드 추가
    [main.cpp]
2025-05-23 fix: test를 위해 queue 사이즈 조절
    feat: 카메라가 꺼질 때 아두이노에 종료 flag 전달
    1. glare의 존재여부가 너무 빠르게 변하는 상황을 방지하기 위해 queue 사이즈를 키움.
    2. 프로그램을 종료(사용 종료) 할 때 선바이저가 기본 위치로 돌아갈 수 있게끔
    종료 flag 전달
    [main.cpp]
2025-05-23 fix: queue 구조 변경
    Threshold로 T/F로만 glare의 유무를 판정했다면 중간에 여유를 두어 queue에 valid True가 매우 적을 때만 glare가 없다고 판단하도록 변경.
    queue에 여유 영역에 valid True가 해당되면 기존의 glare위치를 그대로 반환
    [main.cpp]
2025-05-24 test: 디버깅 용 테스트 코드 추가 (5/19 기준 코드)
2025-05-24 feat: 그리드 좌표 시각화 모듈 추가 및 메인 제어 루프에 통합
2025-05-25 test: 테스트용 그리드 시각화 모듈 오류 수정
    [main.cpp]
2025-05-27 fix: queue 구조 수정
    [main.cpp]
2025-05-27 fix: merge과정에서 생긴 오류 수정
    [main.cpp]
2025-05-27 fix: merge 과정에서 생긴 오류 수정
    이후 종현이랑 추가로 코드 수정 필요해 보임
    [main.cpp]
2025-05-29 feat: 차량 전방 밝기 상태 확인하는 함수 추가 fix: main.cpp 및 return_position.cpp 코드 merge 이전으로 롤백
    차량 전방 밝기를 판단할 때 태양을 직접 보게 될 경우 주변이 어두워지는 문제 발생. 이를 표준편차를 구하는 방식으로 해결하고자 함. 표준편차가 크면 glare가 존재하는 경우로 인식식
    [main.cpp]
2025-05-30 fix: 표준편차 Threshold 값 설정 및 priority Threshold 값 수정
    [main.cpp]
2025-05-30 chore: 메인 제어 루프 검사 대상 제외
2025-05-30 feat: 시리얼 통신 활성화 및 그리드 좌표 테스트 모듈 활성화 모드 추가
2025-05-30 feat: pitch 변환 로직 추가
2025-05-30 chore: 상수값 1차 확정 및 pitch 상수 추가가
2025-05-30 feat: 빌드시 두 개의 테스트 모듈 모두 컴파일되도록 수정
2025-05-30 feat: 캘리브레이션용 함수 추가
2025-05-30 docs: 캘리브레이션용 함수 사용법 명시
2025-05-30 chore: 필요없어진 환경 설정 파일 제거
2025-05-30 docs: 배포용 README 초안 작성
2025-05-31 fix: 테스트 모듈 함수 인자 수정
    [main.cpp]
2025-05-31 fix: 함수 인자 참조 오류 수정
    [calibration.py]
2025-05-31 fix: 테스트용 코드 통합 중 버그 발생 이에 대한 수정
    [main.cpp]
2025-05-31 chore: 2차 통합 테스트 중 파라미터 수정
    [main.cpp]
2025-06-08 chore : glare evaluate.cpp & 테스트 파일 위치 변경
2025-06-08 chore : test image 추가
2025-06-09 fix: queue 구조 수정
    - queue에 glare의 좌표를 저장할 때의 조건을 변경
    - Threshold 변경
    [main.cpp]
2025-06-15 fix: 하드웨어 흐름 제어 활성화
2025-06-15 fix: min, time 값 변경
2025-06-15 fix: 잘 돌아가던 상황과 모드 통일
2025-06-20 chore : glare detect 평가를 위한 데이터 및 코드 추가
2025-06-20 feat: 시리얼 통신 논블로킹 모드로 변경
2025-06-20 fix: 코드 정리 및 주석 재구성
    [main.cpp]
2025-06-20 chore: 캐드 파일 원격 저장소 저장을 위한 Git LFS 설정 및 파일 업로드
    [ArduinoMega.ipt, CREAİLTY 4234.0002.ipt, Conect_link_Right.0002.ipt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]
2025-06-20 docs: README 시연 영상(초안), 포스터, 팀원 이메일 추가
2025-06-20 docs: README 시연 영상 썸네일 구문 추가
2025-06-20 docs: 어색한 줄바꿈 수정
2025-06-20 fix: 시리얼 포트 파일 디스크립터 변수 정적 변수화 및 일관되게 수정
2025-06-22 fix: 노출 값 수정 및 주석 재구성
    [main.cpp]
2025-06-22 fix: 변수 이름 설정 오류 해결
2025-06-22 chore: 디버깅 코드 제외
    - 실제 프로그램 동작에 필요한 main.py만 남기도록 코드 정리
2025-07-28 fix: RPi와 Arduino 간 통신 불안정성 해결 Baud rate를 115200에서 9600으로 줄이고, 통신 프로토콜을 기존 매루프마다 통신을 항상 시도했던 것에서 RPi 측에서 통신 필요여부를 판단하고 송신하는 것으로 변경.
2025-07-28 fix: 카메라 설정 오류 수정
2025-07-28 fix: 카메라 설정 오류 수정 및 통신 불안정성 해결
    [main.cpp]
2025-07-28 docs: 유튜브 URL 최종 시연 영상으로 수정
